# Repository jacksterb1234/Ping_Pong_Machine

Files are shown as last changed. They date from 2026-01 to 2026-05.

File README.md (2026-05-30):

# Ping Pong Machine — Table Tennis Serving Robot

A fully custom table tennis serving robot designed for serve-receive practice. Features dual-axis spin control (pitch and yaw), a printed spindexer, and a Bluetooth mobile app for wireless control. Powered entirely from a single USB-C connection.

## Features

- **Dual-axis spin control** — independent pitch and yaw adjustment for realistic serve variation
- **Printed spindexer** — feeds and spins balls for consistent delivery
- **Bluetooth control** via a custom mobile app (Expo/React Native) for easy wireless operation
- **USB-C powered** — single cable for full system power
- **Modular electronics design:**
  - USB-C PD power negotiation board
  - Motor and microcontroller breakout board
  - Buck voltage regulation board
- Designed and fabricated with **JLCPCB** for PCB production

## Repository Structure

```
Ping_Pong_Machine/
├── Kicad/               # KiCad PCB projects (power, motor breakout, buck reg)
├── Code/                # Microcontroller firmware and Bluetooth app code
├── CAD/                 # 3D-printable parts (spindexer, frame, wheels)
├── Sims/                # Simulations for board fit and assembly
└── ul_PTPS543021DRLR/   # Custom KiCad footprint
```

## Electronics

| Board | Function |
|---|---|
| USB-C PD board | Negotiates input voltage from USB-C PD source |
| Motor breakout | Drives launch and spin motors |
| MCU breakout | Hosts microcontroller and Bluetooth module |
| Buck regulator | Steps down voltage for logic-level components |

## Mobile App

Controlled via a custom **React Native (Expo)** app that connects over Bluetooth. The app allows users to adjust spin type, speed, and frequency from their phone—no physical controls on the machine required.

## Tools Used

- **KiCad** — PCB schematic and layout
- **JLCPCB** — PCB fabrication and SMT assembly
- **Fusion360 / SolidWorks** — Mechanical CAD (frame and launcher)
- **Expo (React Native)** — Mobile app development

## Author

**Jackson Barber** — [github.com/jacksterb1234](https://github.com/jacksterb1234)

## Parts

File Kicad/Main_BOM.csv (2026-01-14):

Id | Designator | Footprint | Quantity | Designation | Supplier and ref
1 | U5 | Vishay_MINICAST-3Pin | 1 | TSOP382xx
2 | C2,C3 | C_0603_1608Metric | 2 | 0.1u
3 | R1 | R_0603_1608Metric | 1 | 10k
4 | U3 | ESP32_30pin | 1 | ~
5 | C5,C1 | C_0603_1608Metric | 2 | 10u
6 | A1 | Pololu_Breakout-16_15.2x20.3mm | 1 | Pololu_Breakout_A4988
7 | C4 | C_0603_1608Metric | 1 | 100u
8 | C7 | C_0603_1608Metric | 1 | 2.2u
9 | J4,J5 | PinHeader_1x04_P2.54mm_Vertical | 2 | Conn_01x04_Pin
10 | C6 | C_0603_1608Metric | 1 | 0.01u
11 | J2,J1 | TerminalBlock_RND_205-00232_1x02_P5.08mm_Horizontal | 2 | Screw_Terminal_01x02
12 | U2 | TSSOP-16_4.4x5mm_P0.65mm | 1 | DRV8833PW
13 | J3 | TerminalBlock_Phoenix_MKDS-3-4-5.08_1x04_P5.08mm_Horizontal | 1 | Screw_Terminal_01x04

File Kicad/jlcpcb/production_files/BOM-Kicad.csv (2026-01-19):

Comment | Designator | Footprint | LCSC | Quantity
100nF | C2,C3 | C_0805_2012Metric_Pad1.18x1.45mm_HandSolder | C14663 | 2
10kΩ | R1 | R_0805_2012Metric_Pad1.20x1.40mm_HandSolder | C25804 | 1
10nF | C6 | C_0805_2012Metric_Pad1.18x1.45mm_HandSolder | C57112 | 1
10uF | C1,C5 | C_0805_2012Metric_Pad1.18x1.45mm_HandSolder | C19702 | 2
2.2uF | C7 | C_0805_2012Metric_Pad1.18x1.45mm_HandSolder | C23630 | 1
TSOP382xx | U5 | Vishay_MINICAST-3Pin |  | 1
~ | U3 | ESP32_30pin |  | 1
Pololu_Breakout_A4988 | A1 | Pololu_Breakout-16_15.2x20.3mm |  | 1
100u | C4 | C_Radial_D8.0mm_H11.5mm_P3.50mm |  | 1
Conn_01x04_Pin | J4 | PinHeader_1x04_P2.54mm_Vertical |  | 1
Screw_Terminal_01x02 | J2 | TerminalBlock_RND_205-00045_1x02_P5.00mm_Horizontal |  | 1
DRV8833PW | U2 | TSSOP-16_4.4x5mm_P0.65mm |  | 1
Screw_Terminal_01x02 | J1 | TerminalBlock_RND_205-00045_1x02_P5.00mm_Horizontal |  | 1
Screw_Terminal_01x04 | J3 | TerminalBlock_RND_205-00003_1x04_P5.00mm_Horizontal |  | 1
Conn_01x04_Pin | J5 | PinHeader_1x04_P2.54mm_Vertical |  | 1

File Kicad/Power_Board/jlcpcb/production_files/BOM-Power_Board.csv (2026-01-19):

Comment | Designator | Footprint | LCSC | Quantity
100kΩ | R4,R7 | R_0805_2012Metric_Pad1.20x1.40mm_HandSolder | C25803 | 2
100nF | C2,C3,C6 | C_0805_2012Metric_Pad1.18x1.45mm_HandSolder | C14663 | 3
100pF | C8 | C_0805_2012Metric_Pad1.18x1.45mm_HandSolder | C14858 | 1
10uF | C1 | C_0805_2012Metric_Pad1.18x1.45mm_HandSolder | C96446 | 1
22kΩ | R5 | R_0805_2012Metric_Pad1.20x1.40mm_HandSolder | C31850 | 1
22uF | C7 | C_0805_2012Metric_Pad1.18x1.45mm_HandSolder | C45783 | 1
47uF | C4 | C_0805_2012Metric_Pad1.18x1.45mm_HandSolder | C16780 | 1
5.1kΩ | R8 | R_0805_2012Metric_Pad1.20x1.40mm_HandSolder | C23186 | 1
68pF | C5 | C_0805_2012Metric_Pad1.18x1.45mm_HandSolder | C28262 | 1
6.8uH | L1 | L_TDK_VLS6045EX_VLS6045AF |  | 1
PTPS543021DRLR | U2 | DRL0006A-MFG |  | 1
Screw_Terminal_01x02 | J2 | TerminalBlock_RND_205-00045_1x02_P5.00mm_Horizontal |  | 1
4.7uH | L2 | L_TDK_VLS6045EX_VLS6045AF |  | 1
Conn_01x04_Pin | J1 | PinSocket_1x04_P2.54mm_Vertical |  | 1
PTPS543021DRLR | U1 | DRL0006A-MFG |  | 1

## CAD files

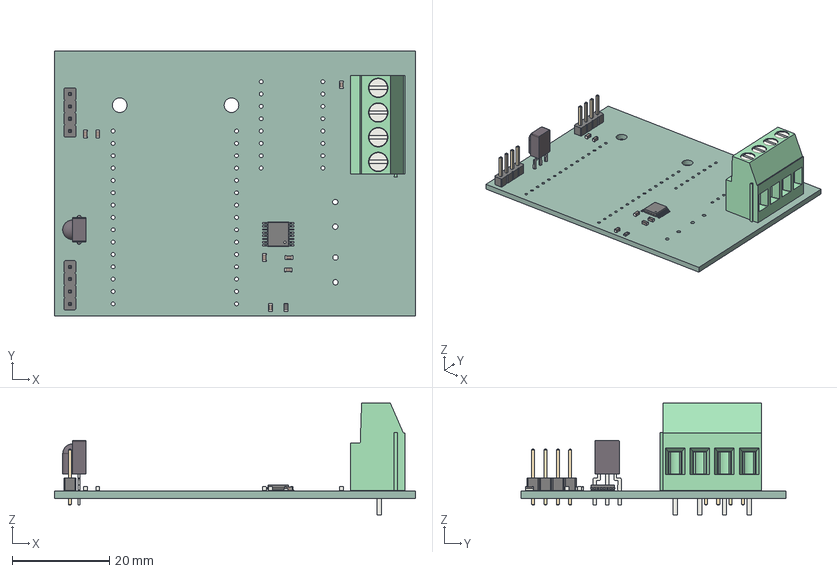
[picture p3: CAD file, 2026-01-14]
CAD/Boards/Main_Board.step
74.3 x 54.6 x 23.0 mm
Vishay_MINICAST-3Pin
C_0603_1608Metric x 7
R_0603_1608Metric
PinHeader_1x04_P2.54mm_Vertical x 2
TSSOP-16_4.4x5mm_P0.65mm
TerminalBlock_Phoenix_MKDS-3-4-5.08_1x04_P5.08mm_Horizontal
Kicad_PCB

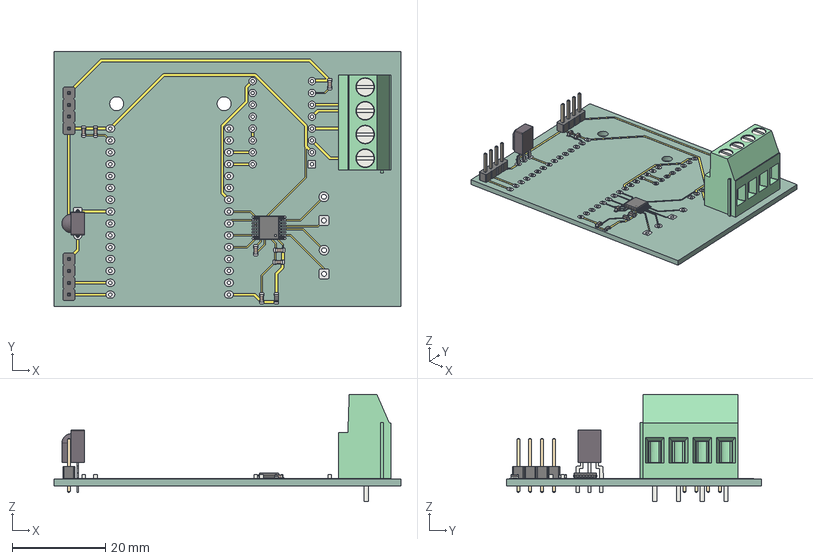
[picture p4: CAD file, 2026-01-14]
CAD/Boards/Main_For_Sim.step
74.3 x 54.6 x 23.0 mm
Vishay_MINICAST-3Pin
C_0603_1608Metric x 7
R_0603_1608Metric
PinHeader_1x04_P2.54mm_Vertical x 2
TSSOP-16_4.4x5mm_P0.65mm
TerminalBlock_Phoenix_MKDS-3-4-5.08_1x04_P5.08mm_Horizontal
Kicad_copper
Kicad_pad
Kicad_via
Kicad_PCB

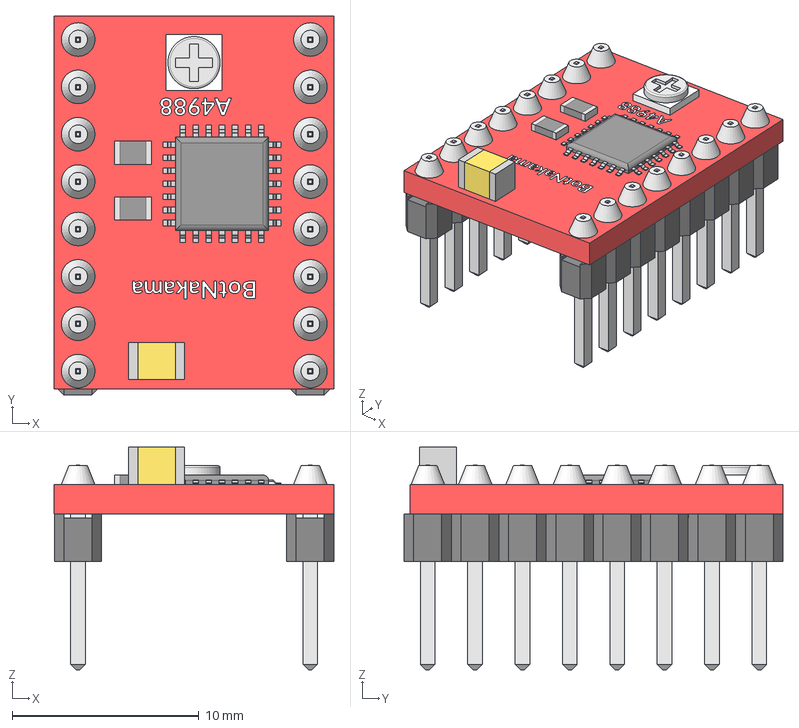
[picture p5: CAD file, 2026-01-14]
CAD/Boards/A4988.stp
15.0 x 20.3 x 11.9 mm
Integrado
Cubo001
BotNakama
A4988_1

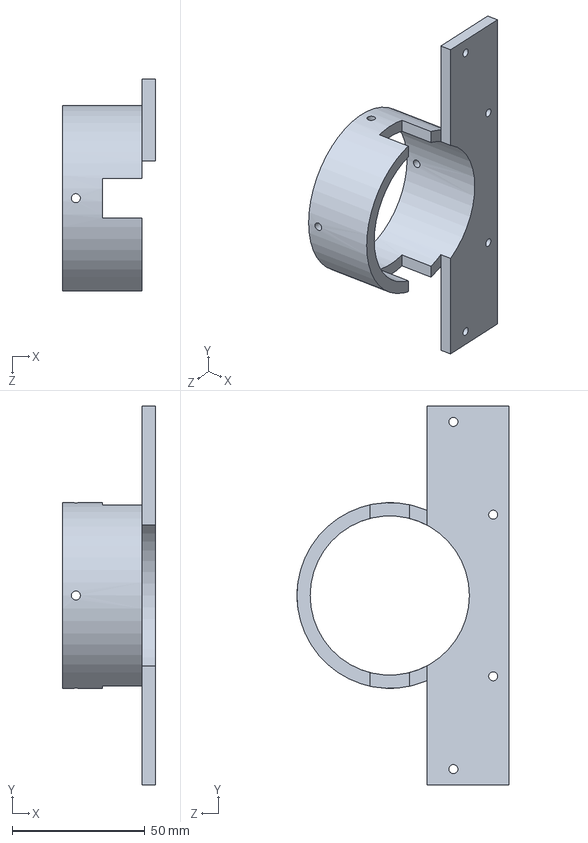
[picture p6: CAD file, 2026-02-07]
CAD/Ping_Pong_P004_Motor_Plate.SLDPRT
35.0 x 143.0 x 80.0 mm

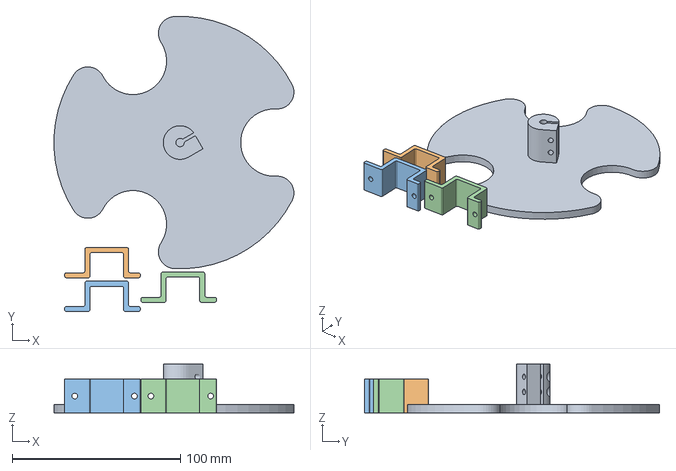
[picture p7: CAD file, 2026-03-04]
CAD/Prints/Ping_Pong_P003_Spindexer_Coupler_Print.3mf
142.6 x 175.3 x 29.0 mm
Ping_Pong_P003_Spindexer_Coupler_Print.STL
Ping_Pong_P005_Motor_Retainer_Print.STL x 3

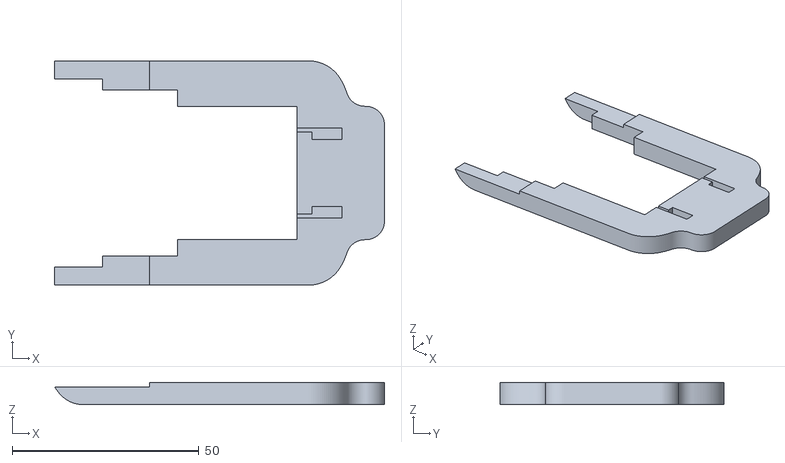
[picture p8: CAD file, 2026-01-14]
CAD/Boards/Base_to_1.5mm2.stl
88.3 x 60.0 x 6.00

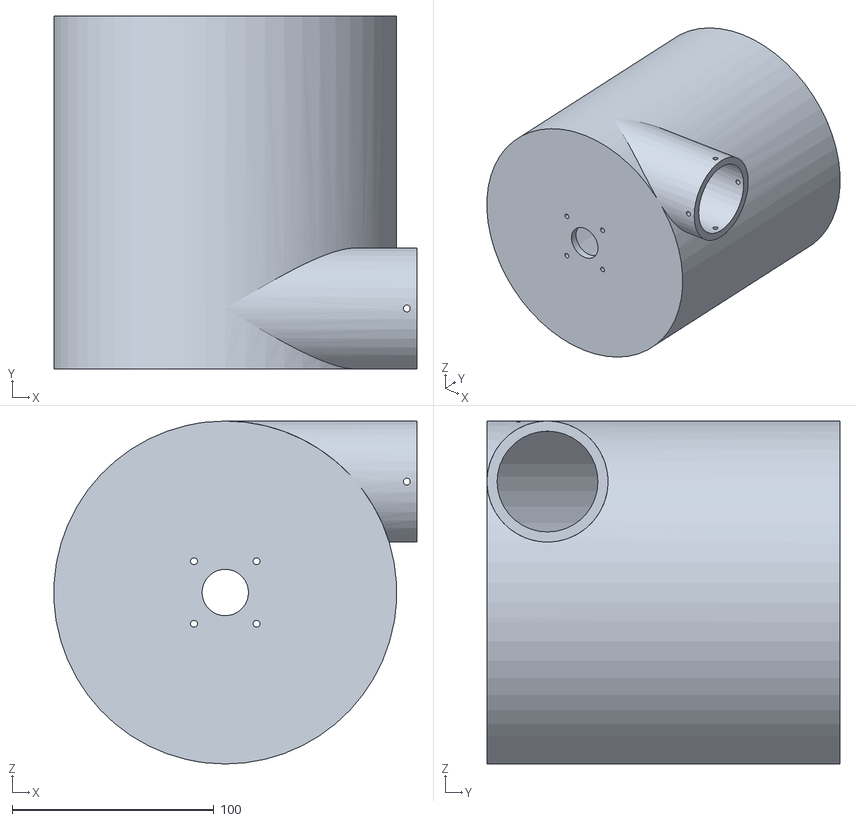
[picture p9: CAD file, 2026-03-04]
CAD/Prints/Ping_Pong_P002_Bin_Print.STL
179.9 x 175.0 x 170.0

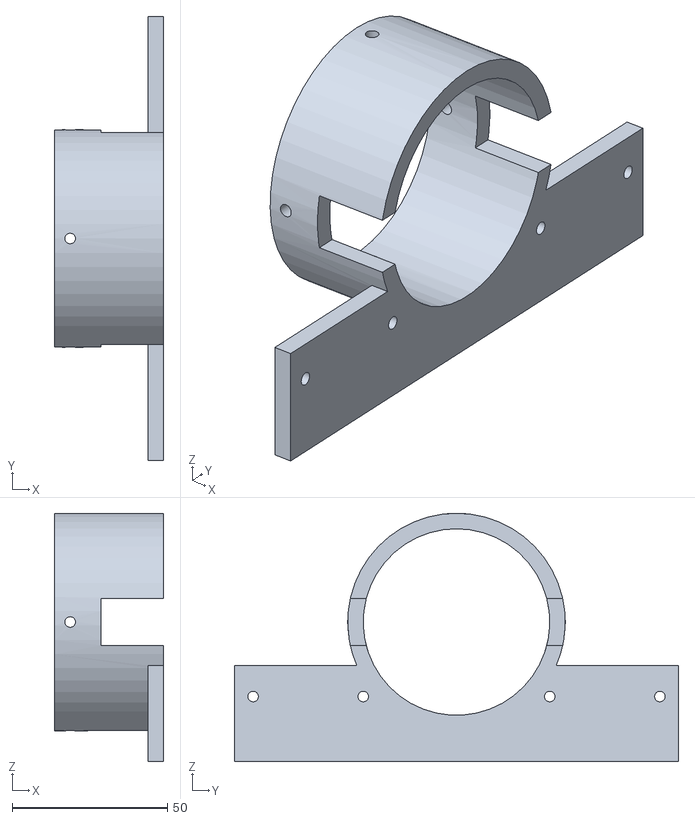
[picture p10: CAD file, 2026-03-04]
CAD/Prints/Ping_Pong_P004_Motor_Plate_Print.STL
35.0 x 143.0 x 80.0

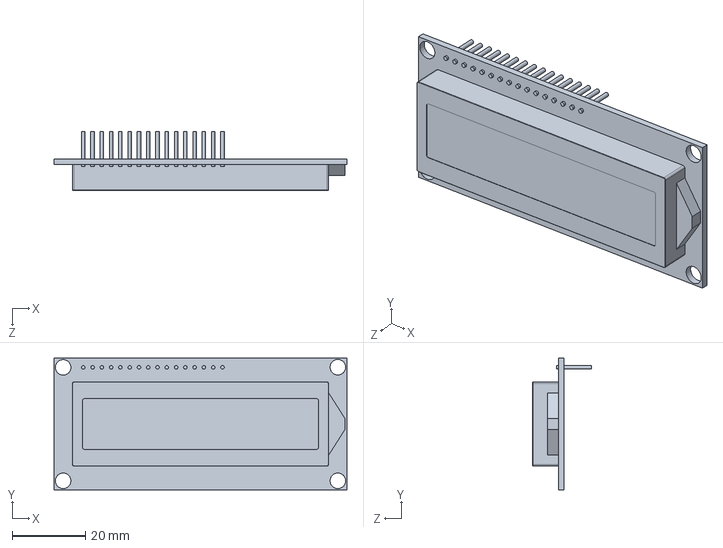
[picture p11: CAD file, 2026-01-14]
CAD/Boards/LCD.SLDPRT
80.0 x 36.0 x 16.0 mm

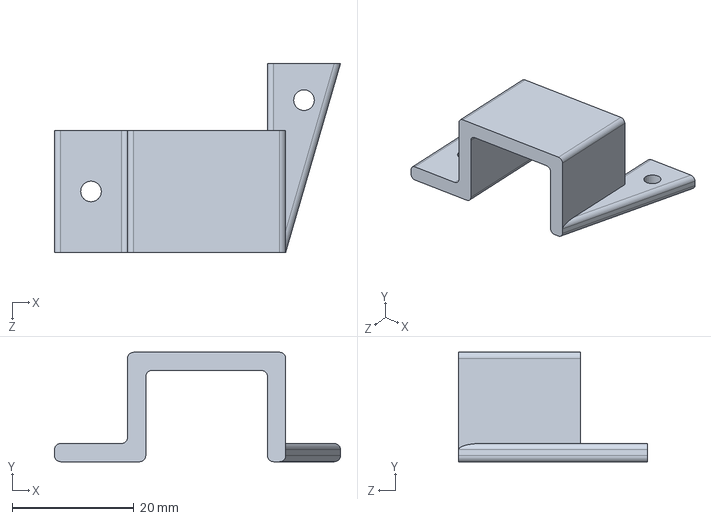
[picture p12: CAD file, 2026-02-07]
CAD/Ping_Pong_P005_Motor_Retainer.SLDPRT
47.0 x 18.0 x 31.0 mm

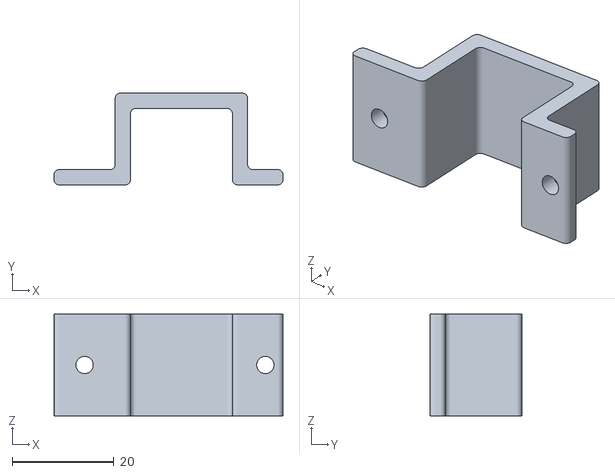
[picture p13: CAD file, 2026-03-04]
CAD/Prints/Ping_Pong_P005_Motor_Retainer_Print.STL
44.9 x 18.0 x 20.0

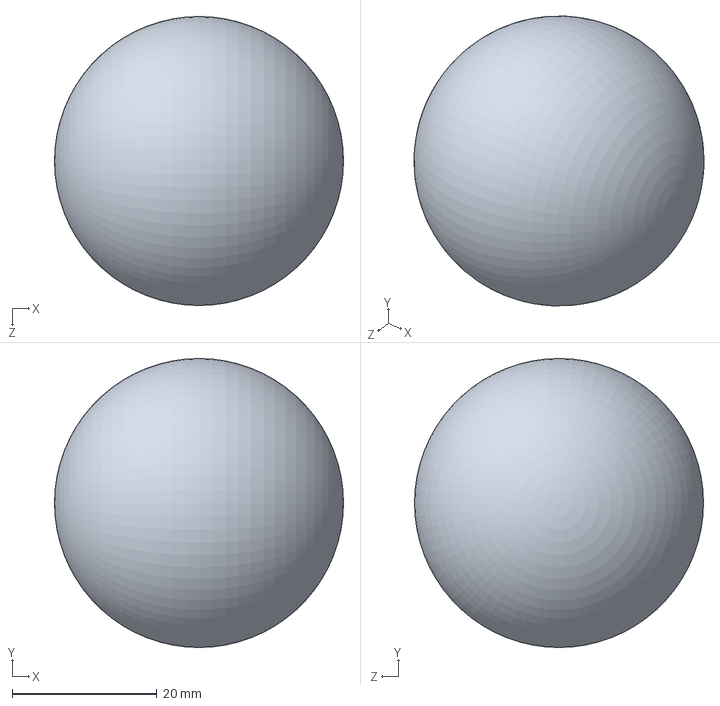
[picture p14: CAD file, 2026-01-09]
CAD/Ping_Pong_P001_Ball.SLDPRT
40.0 x 40.0 x 40.0 mm

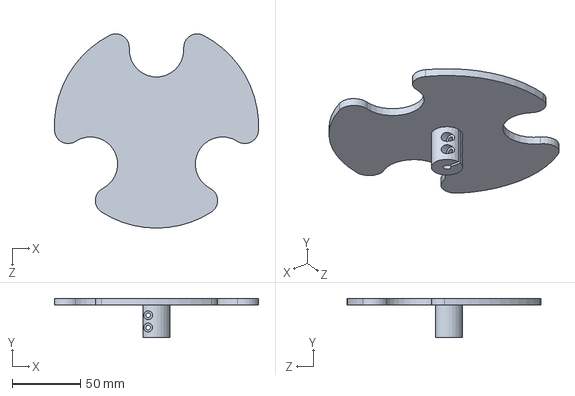
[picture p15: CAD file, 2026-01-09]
CAD/Ping_Pong_P003_Spindexer_Coupler.SLDPRT
149.9 x 29.0 x 142.7 mm

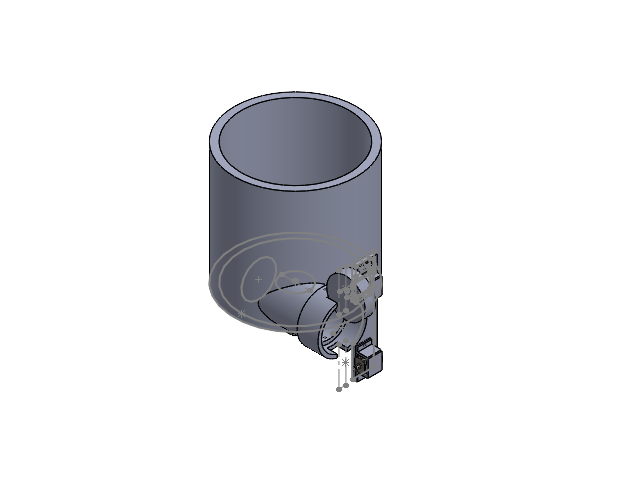
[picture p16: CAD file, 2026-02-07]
CAD/Ping_Pong_A001_MAIN.SLDASM
Ping_Pong_P002_Bin
Ping_Pong_P001_Ball
6627T91_Stepper Motor
Ping_Pong_P003_Spindexer_Coupler
Ping_Pong_P004_Motor_Plate
CommutatorHousing.STEP x 2
StatorHousing.STEP x 2
Gear6.STEP x 2
Ping_Pong_P005_Motor_Retainer
Ping_Pong_P006_Wheel_Mockup
MirrorPing_Pong_P005_Motor_Retainer

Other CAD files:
CAD/Boards/Ping_Pong_Board_A001_MAIN.SLDASM
CAD/Boards/R_0603_1608Metric_1.step.SLDPRT
CAD/MirrorPing_Pong_P005_Motor_Retainer.SLDPRT
CAD/Boards/R_0603_1608Metric_2.step.SLDPRT
CAD/6627T91_Stepper Motor.SLDPRT
CAD/Boards/C_0603_1608Metric_1.step.SLDPRT
CAD/Boards/C_0603_1608Metric_2.step.SLDPRT
CAD/Boards/DeWalt 10AH 20V Battery.step
CAD/Boards/L_0603_1608Metric_1.step.SLDPRT
CAD/Boards/PinHeader_1x04_P2.54mm_Vertical_1.step.SLDPRT
CAD/Boards/Power_Board.step
CAD/Boards/Power_Board_For_Sim.step
CAD/Boards/Power_Board_PCB_1.step.SLDPRT
CAD/Boards/TerminalBlock_Phoenix_MKDS-1,5-2-5.08_1x02_P5.08mm_Horizontal_1.step.SLDPRT
CAD/Boards/esp32_Wroom_30pins_C-Type.STEP
CAD/Ping_Pong_P002_Bin.SLDPRT
CAD/Ping_Pong_P006_Wheel_Mockup.SLDPRT
CAD/Prints/Ping_Pong_P003_Spindexer_Coupler_Print.STL

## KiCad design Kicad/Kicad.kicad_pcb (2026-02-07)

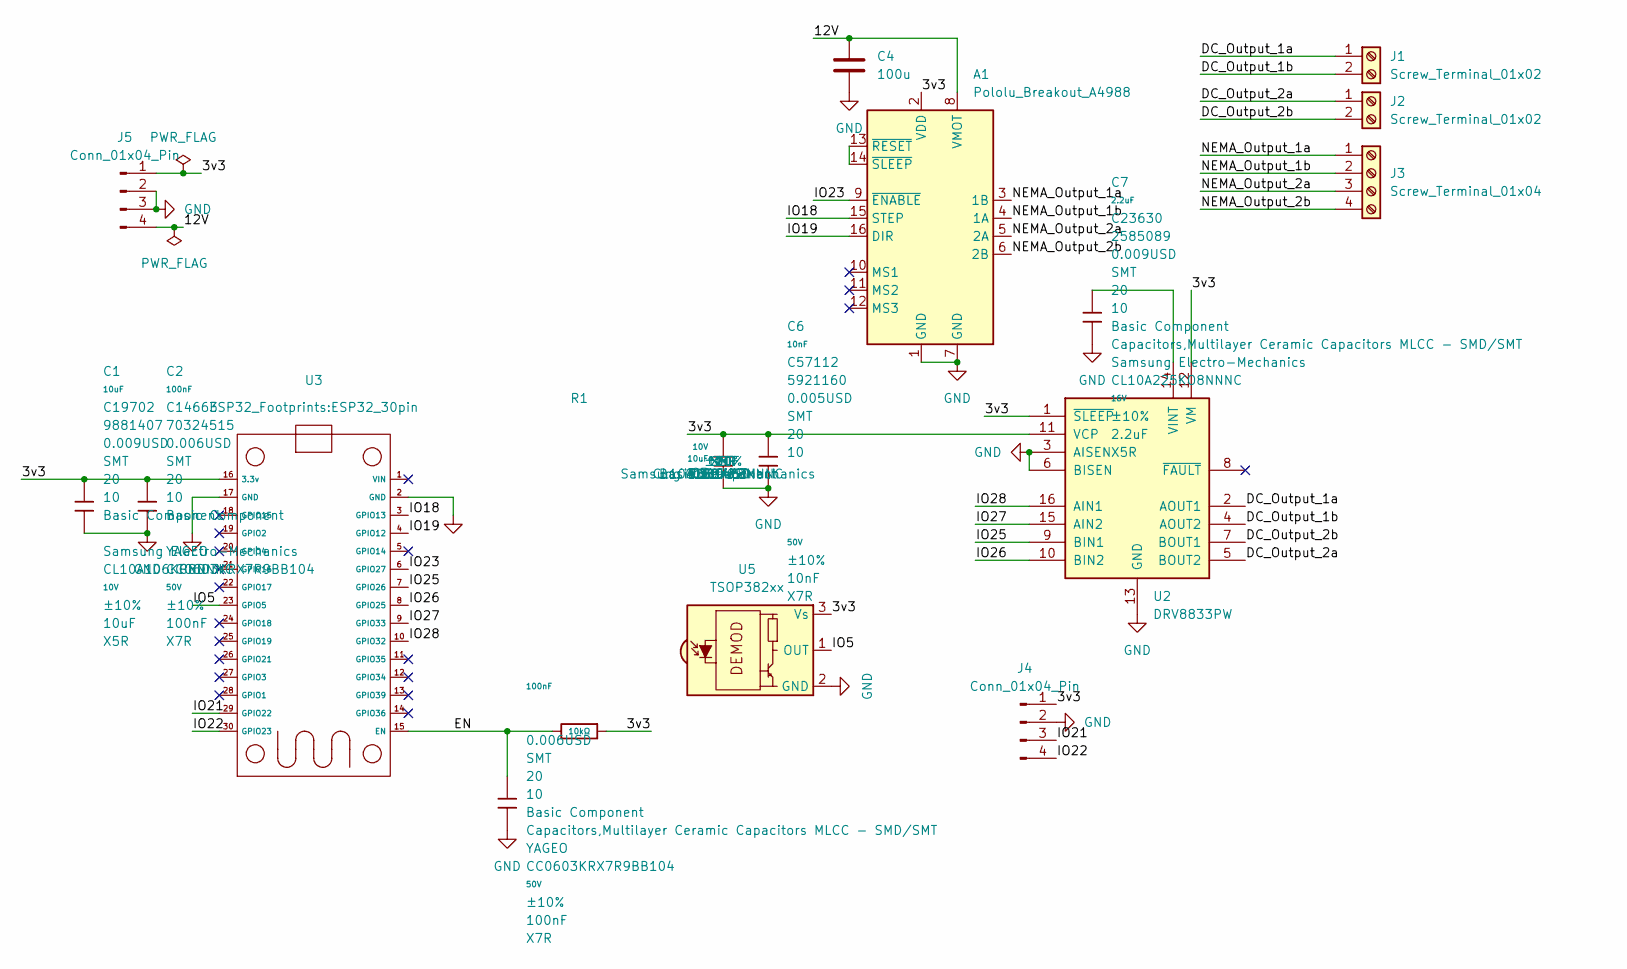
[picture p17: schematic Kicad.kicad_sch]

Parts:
A1: Pololu_Breakout_A4988; Pololu_Breakout-16_15.2x20.3mm
C1, C5: 10uF; C_0805_2012Metric_Pad1.18x1.45mm_HandSolder; Voltage Rated 10V; Tolerance ±10%; Part CL10A106KP8NNNC; LCSC C19702
C2, C3: 100nF; C_0805_2012Metric_Pad1.18x1.45mm_HandSolder; Voltage Rated 50V; Tolerance ±10%; Part CC0603KRX7R9BB104; LCSC C14663
C4: 100u; C_Radial_D8.0mm_H11.5mm_P3.50mm
C6: 10nF; C_0805_2012Metric_Pad1.18x1.45mm_HandSolder; Voltage Rated 50V; Tolerance ±10%; Part 0603B103K500NT; LCSC C57112
C7: 2.2uF; C_0805_2012Metric_Pad1.18x1.45mm_HandSolder; Voltage Rated 16V; Tolerance ±10%; Part CL10A225KO8NNNC; LCSC C23630
J1, J2: Screw_Terminal_01x02; TerminalBlock_RND_205-00045_1x02_P5.00mm_Horizontal
J3: Screw_Terminal_01x04; TerminalBlock_RND_205-00003_1x04_P5.00mm_Horizontal
J4, J5: Conn_01x04_Pin; PinHeader_1x04_P2.54mm_Vertical
R1: 10kΩ; R_0805_2012Metric_Pad1.20x1.40mm_HandSolder; Overload Voltage (Max) 75V; Tolerance ±1%; Part 0603WAF1002T5E; LCSC C25804
U2: DRV8833PW; TSSOP-16_4.4x5mm_P0.65mm
U3: ESP32_30pin
U5: TSOP382xx; Vishay_MINICAST-3Pin

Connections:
/3v3: A1.2 (VDD), C1.2, C2.2, C5.2, C6.2, J4.1, J5.1, R1.1, U2.1 (~SLEEP), U2.11 (VCP), U2.12 (VM), U3.16 (3.3v), U5.3 (Vs)
/12V: A1.8 (VMOT), C4.2, J5.4
/DC_Output_1a: J1.1, U2.2 (AOUT1)
/DC_Output_1b: J1.2, U2.4 (AOUT2)
/DC_Output_2a: J2.1, U2.5 (BOUT2)
/DC_Output_2b: J2.2, U2.7 (BOUT1)
/EN: C3.1, R1.2, U3.15 (EN)
/IO5: U3.23 (GPIO5), U5.1 (OUT)
/IO18: A1.15 (STEP), U3.3 (GPIO13)
/IO19: A1.16 (DIR), U3.4 (GPIO12)
/IO21: J4.3, U3.29 (GPIO22)
/IO22: J4.4, U3.30 (GPIO23)
/IO23: A1.9 (~ENABLE), U3.6 (GPIO27)
/IO25: U2.9 (BIN1), U3.7 (GPIO26)
/IO26: U2.10 (BIN2), U3.8 (GPIO25)
/IO27: U2.15 (AIN2), U3.9 (GPIO33)
/IO28: U2.16 (AIN1), U3.10 (GPIO32)
/NEMA_Output_1a: A1.3 (1B), J3.1
/NEMA_Output_1b: A1.4 (1A), J3.2
/NEMA_Output_2a: A1.5 (2A), J3.3
/NEMA_Output_2b: A1.6 (2B), J3.4
GND: A1.1 (GND), A1.7 (GND), C1.1, C2.1, C3.2, C4.1, C5.1, C6.1, C7.1, J4.2, J5.2, J5.3, U2.3 (AISEN), U2.6 (BISEN), U2.13 (GND), U3.2 (GND), U3.17 (GND), U5.2 (GND)
unnamed: A1.13 (~RESET), A1.14 (~SLEEP)
unnamed: C7.2, U2.14 (VINT)

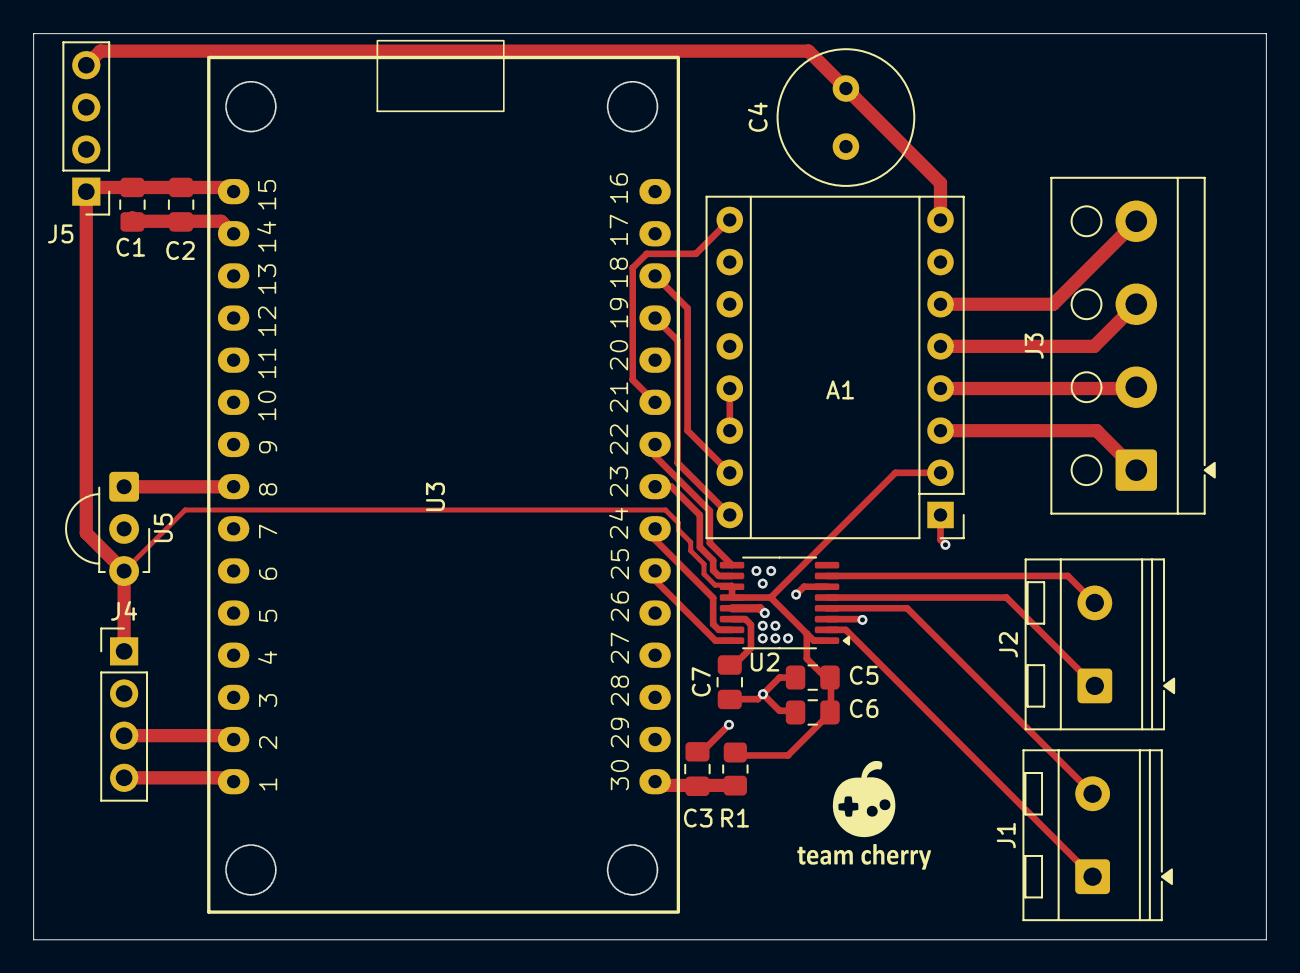
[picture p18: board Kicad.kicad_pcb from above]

Board: 2 copper layers, 74.3 x 54.6 mm, 17 parts (0 on the bottom side), 24 nets.

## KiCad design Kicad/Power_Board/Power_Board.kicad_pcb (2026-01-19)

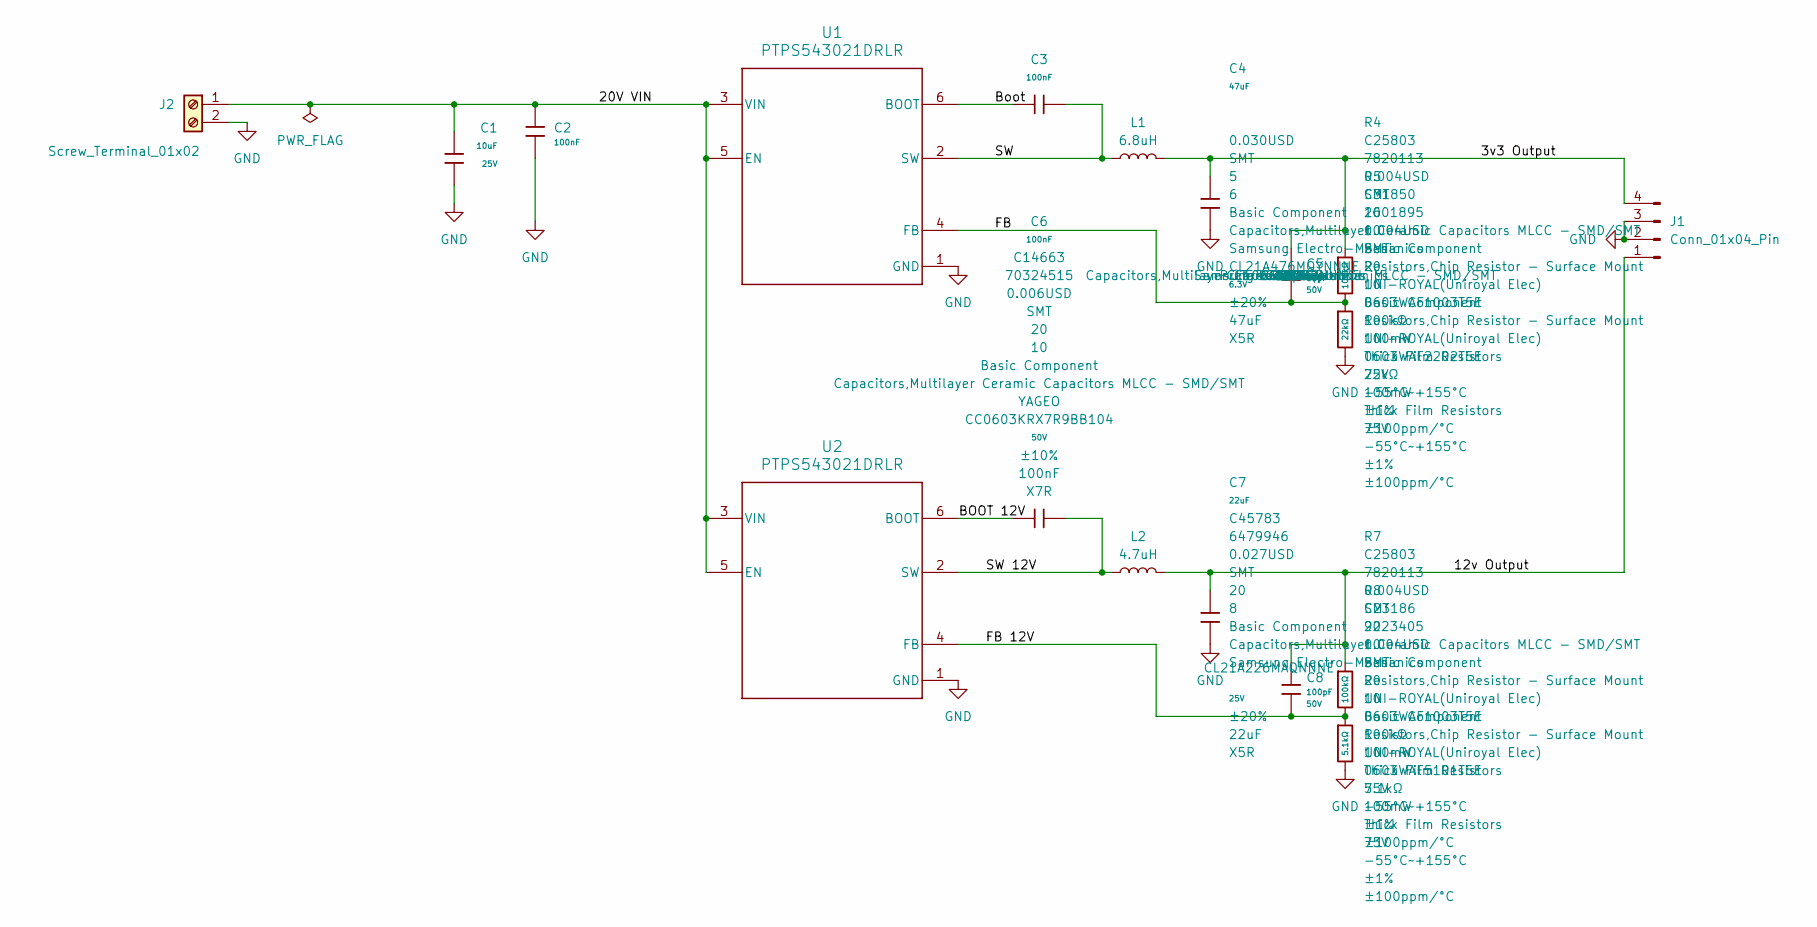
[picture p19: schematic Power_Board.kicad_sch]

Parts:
C1: 10uF; C_0805_2012Metric_Pad1.18x1.45mm_HandSolder; Voltage Rated 25V; Tolerance ±20%; Part CL10A106MA8NRNC; LCSC C96446
C2, C3, C6: 100nF; C_0805_2012Metric_Pad1.18x1.45mm_HandSolder; Voltage Rated 50V; Tolerance ±10%; Part CC0603KRX7R9BB104; LCSC C14663
C4: 47uF; C_0805_2012Metric_Pad1.18x1.45mm_HandSolder; Voltage Rated 6.3V; Tolerance ±20%; Part CL21A476MQYNNNE; LCSC C16780
C5: 68pF; C_0805_2012Metric_Pad1.18x1.45mm_HandSolder; Voltage Rated 50V; Tolerance ±5%; Part CL10C680JB8NNNC; LCSC C28262
C7: 22uF; C_0805_2012Metric_Pad1.18x1.45mm_HandSolder; Voltage Rated 25V; Tolerance ±20%; Part CL21A226MAQNNNE; LCSC C45783
C8: 100pF; C_0805_2012Metric_Pad1.18x1.45mm_HandSolder; Voltage Rated 50V; Tolerance ±5%; Part CL10C101JB8NNNC; LCSC C14858
J1: Conn_01x04_Pin; PinSocket_1x04_P2.54mm_Vertical
J2: Screw_Terminal_01x02; TerminalBlock_RND_205-00045_1x02_P5.00mm_Horizontal
L1: 6.8uH; L_TDK_VLS6045EX_VLS6045AF
L2: 4.7uH; L_TDK_VLS6045EX_VLS6045AF
R4, R7: 100kΩ; R_0805_2012Metric_Pad1.20x1.40mm_HandSolder; Overload Voltage (Max) 75V; Tolerance ±1%; Part 0603WAF1003T5E; LCSC C25803
R5: 22kΩ; R_0805_2012Metric_Pad1.20x1.40mm_HandSolder; Overload Voltage (Max) 75V; Tolerance ±1%; Part 0603WAF2202T5E; LCSC C31850
R8: 5.1kΩ; R_0805_2012Metric_Pad1.20x1.40mm_HandSolder; Overload Voltage (Max) 75V; Tolerance ±1%; Part 0603WAF5101T5E; LCSC C23186
U1, U2: PTPS543021DRLR; DRL0006A-MFG

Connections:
/3v3 Output: C4.1, C5.1, J1.4, L1.2, R4.1
/12v Output: C7.1, C8.1, J1.1, L2.2, R7.1
/20V VIN: C1.1, C2.1, J2.1, U1.3 (VIN), U1.5 (EN), U2.3 (VIN), U2.5 (EN)
/BOOT 12V: C6.1, U2.6 (BOOT)
/Boot: C3.1, U1.6 (BOOT)
/FB: C5.2, R4.2, R5.1, U1.4 (FB)
/FB 12V: C8.2, R7.2, R8.1, U2.4 (FB)
/SW: C3.2, L1.1, U1.2 (SW)
/SW 12V: C6.2, L2.1, U2.2 (SW)
GND: C1.2, C2.2, C4.2, C7.2, J1.2, J1.3, J2.2, R5.2, R8.2, U1.1 (GND), U2.1 (GND)

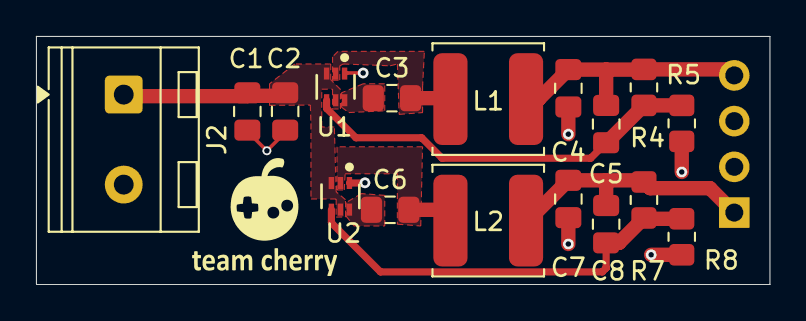
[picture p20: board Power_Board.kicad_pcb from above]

Board: 2 copper layers, 40.8 x 13.8 mm, 18 parts (1 on the bottom side), 10 nets.

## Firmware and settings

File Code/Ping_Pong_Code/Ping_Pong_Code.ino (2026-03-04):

#include <Arduino.h>

#define DECODE_NEC
#include <IRremote.hpp>

#include <Wire.h>
#include <LiquidCrystal_I2C.h>

// --- BLE ---
#include <BLEDevice.h>
#include <BLEServer.h>
#include <BLEUtils.h>
#include <BLE2902.h>

// -------------------- PINS --------------------
const int IR_PIN = 5;

// A4988
const int STEP_PIN = 13;
const int DIR_PIN  = 12;
const int EN_PIN   = 27;
const bool A4988_ENABLE_ACTIVE_LOW = true;

// DRV8833
const int AIN1 = 32;
const int AIN2 = 33;
const int BIN1 = 26;
const int BIN2 = 25;

// LCD
const int LCD_ADDR = 0x27;
// Note: you had (LCD_ADDR, 22, 23) in your code, which is unusual for LiquidCrystal_I2C.
// If that worked for you, keep it. If not, typical call is (LCD_ADDR, 16, 2).
LiquidCrystal_I2C lcd(LCD_ADDR, 16, 2);

// DC Speed Setup
const uint32_t DC_PWM_FREQ = 20000;
const uint8_t  DC_PWM_RES  = 8;
uint8_t dc1Speed = 180;
uint8_t dc2Speed = 180;

// IR commands
const uint8_t IR_CMD_TOGGLE_STEPPER = 0x10;
const uint8_t IR_CMD_TOGGLE_DCS     = 0x11;
const uint8_t IR_CMD_SERVE_ONE      = 0x12;
const uint8_t IR_CMD_MOTOR1_SPDUP   = 0x13;
const uint8_t IR_CMD_MOTOR1_SLWDWN  = 0x14;
const uint8_t IR_CMD_MOTOR2_SPDUP   = 0x15;
const uint8_t IR_CMD_MOTOR2_SLWDWN  = 0x16;

// Stepper control
const int STEPS_PER_SERVE = 800;
const int STEP_DELAY_US   = 800;

// State
bool stepperEnabled = false;
bool dcMotorsOn     = false;
int  ballsServed    = 0;

// --- BLE UUIDs (match Expo app) ---
#define SERVICE_UUID   "0000FFFF-0000-1000-8000-00805F9B34FB"
#define CMD_CHAR_UUID  "0000FF01-0000-1000-8000-00805F9B34FB"

BLECharacteristic *cmdChar = nullptr;

// Continuous serve state
bool     continuousOn        = false;
uint32_t continuousIntervalMs = 400;
uint32_t lastServeMs         = 0;

// -------------------- LCD --------------------
void lcdUpdate() {
  lcd.clear();
  lcd.setCursor(0, 0);
  lcd.print("Served: ");
  lcd.print(ballsServed);

  lcd.setCursor(0, 1);
  lcd.print("ST:");
  if (stepperEnabled) lcd.print("ON ");
  else                lcd.print("OFF");

  lcd.print(" DC:");
  if (dcMotorsOn) lcd.print("ON ");
  else            lcd.print("OFF ");

  lcd.print(dc1Speed / 255.0f * 100.0f, 0);
  lcd.print("%,");
  lcd.print(dc2Speed / 255.0f * 100.0f, 0);
  lcd.print("%");
}

// -------------------- Stepper --------------------
void setStepperEnabled(bool on) {
  stepperEnabled = on;
  pinMode(EN_PIN, OUTPUT);

  if (A4988_ENABLE_ACTIVE_LOW) {
    if (on) digitalWrite(EN_PIN, LOW);
    else    digitalWrite(EN_PIN, HIGH);
  } else {
    if (on) digitalWrite(EN_PIN, HIGH);
    else    digitalWrite(EN_PIN, LOW);
  }
}

void stepperMoveSteps(int steps, bool dir) {
  if (!stepperEnabled) return;

  digitalWrite(DIR_PIN, dir ? HIGH : LOW);

  for (int i = 0; i < steps; i++) {
    digitalWrite(STEP_PIN, HIGH);
    delayMicroseconds(STEP_DELAY_US);
    digitalWrite(STEP_PIN, LOW);
    delayMicroseconds(STEP_DELAY_US);
  }
}

// -------------------- DC motors --------------------
void setDc1Speed() {
  digitalWrite(AIN2, LOW);
  analogWrite(AIN1, dc1Speed);
}

void setDc2Speed() {
  digitalWrite(BIN2, LOW);
  analogWrite(BIN1, dc2Speed);
}

void toggleDcMotors() {
  if (dcMotorsOn) {
    analogWrite(AIN1, 0);
    analogWrite(AIN2, 0);
    analogWrite(BIN1, 0);
    analogWrite(BIN2, 0);
  } else {
    setDc1Speed();
    setDc2Speed();
  }
  dcMotorsOn = !dcMotorsOn;
}

// -------------------- Serve --------------------
void serveOneBall() {
  if (!stepperEnabled) setStepperEnabled(true);
  stepperMoveSteps(STEPS_PER_SERVE, true);
  ballsServed++;
  lcdUpdate();
}

// -------------------- IR --------------------
void handleIrCommand(uint8_t cmd) {
  if (cmd == IR_CMD_TOGGLE_STEPPER) {
    setStepperEnabled(!stepperEnabled);
  } else if (cmd == IR_CMD_TOGGLE_DCS) {
    toggleDcMotors();
  } else if (cmd == IR_CMD_SERVE_ONE) {
    serveOneBall();
  } else if (cmd == IR_CMD_MOTOR1_SPDUP) {
    dc1Speed = min<uint8_t>(255, dc1Speed + 25);
    setDc1Speed();
  } else if (cmd == IR_CMD_MOTOR1_SLWDWN) {
    dc1Speed = max<uint8_t>(0, dc1Speed - 25);
    setDc1Speed();
  } else if (cmd == IR_CMD_MOTOR2_SPDUP) {
    dc2Speed = min<uint8_t>(255, dc2Speed + 25);
    setDc2Speed();
  } else if (cmd == IR_CMD_MOTOR2_SLWDWN) {
    dc2Speed = max<uint8_t>(0, dc2Speed - 25);
    setDc2Speed();
  }
  lcdUpdate();
}

// -------------------- BLE command handling --------------------
void handleBleCommand(const String &json) {
  Serial.print("BLE cmd: ");
  Serial.println(json);

  if (json.indexOf("\"type\":\"SERVE_ONE\"") >= 0) {
    serveOneBall();
  }
  else if (json.indexOf("\"type\":\"TOGGLE_DCS\"") >= 0) {
    toggleDcMotors();
    lcdUpdate();
  }
  else if (json.indexOf("\"type\":\"TOGGLE_STEPPER\"") >= 0) {
    setStepperEnabled(!stepperEnabled);
    lcdUpdate();
  }
  else if (json.indexOf("\"type\":\"MOTOR1_SPDUP\"") >= 0) {
    dc1Speed = min<uint8_t>(255, dc1Speed + 25);
    setDc1Speed();
    lcdUpdate();
  }
  else if (json.indexOf("\"type\":\"MOTOR1_SLWDWN\"") >= 0) {
    dc1Speed = max<uint8_t>(0, dc1Speed - 25);
    setDc1Speed();
    lcdUpdate();
  }
  else if (json.indexOf("\"type\":\"MOTOR2_SPDUP\"") >= 0) {
    dc2Speed = min<uint8_t>(255, dc2Speed + 25);
    setDc2Speed();
    lcdUpdate();
  }
  else if (json.indexOf("\"type\":\"MOTOR2_SLWDWN\"") >= 0) {
    dc2Speed = max<uint8_t>(0, dc2Speed - 25);
    setDc2Speed();
    lcdUpdate();
  }
  else if (json.indexOf("\"type\":\"START_CONTINUOUS\"") >= 0) {
    int idx = json.indexOf("\"intervalMs\":");
    if (idx >= 0) {
      int start = idx + String("\"intervalMs\":").length();
      int end = json.indexOf("}", start);
      if (end < 0) end = json.length();
      String num = json.substring(start, end);
      num.trim();
      uint32_t val = num.toInt();
      if (val >= 150 && val <= 3000) {
        continuousIntervalMs = val;
      }
    }
    continuousOn  = true;
    lastServeMs   = millis();
    Serial.println("Continuous mode: ON");
  }
  else if (json.indexOf("\"type\":\"STOP_CONTINUOUS\"") >= 0) {
    continuousOn = false;
    Serial.println("Continuous mode: OFF");
  }
  else {
    Serial.println("Unknown BLE command");
  }
}

class CommandCallback : public BLECharacteristicCallbacks {
  void onWrite(BLECharacteristic *c) override {
    String value = c->getValue();
    if (value.isEmpty()) return;
    String json(value.c_str());
    handleBleCommand(json);
  }
};

// -------------------- Setup --------------------
void setup() {
  Serial.begin(115200);

  // Stepper
  pinMode(STEP_PIN, OUTPUT);
  pinMode(DIR_PIN, OUTPUT);
  setStepperEnabled(false);

  // DC pins
  pinMode(AIN1, OUTPUT);
  pinMode(AIN2, OUTPUT);
  pinMode(BIN1, OUTPUT);
  pinMode(BIN2, OUTPUT);

  // DC PWM (adjust if your core uses ledcAttachPin style instead)
  analogWriteResolution(AIN1, DC_PWM_RES);
  analogWriteFrequency(AIN1, DC_PWM_FREQ);
  analogWriteResolution(BIN1, DC_PWM_RES);
  analogWriteFrequency(BIN1, DC_PWM_FREQ);

  digitalWrite(AIN2, LOW);
  digitalWrite(BIN2, LOW);
  analogWrite(AIN1, 0);
  analogWrite(BIN1, 0);

  // LCD
  lcd.init();
  lcd.backlight();
  lcdUpdate();

  // IR
  IrReceiver.begin(IR_PIN, DISABLE_LED_FEEDBACK);

  // BLE
  BLEDevice::init("PingPongRobot");
  BLEServer *server = BLEDevice::createServer();
  BLEService *service = server->createService(SERVICE_UUID);

  cmdChar = service->createCharacteristic(
    CMD_CHAR_UUID,
    BLECharacteristic::PROPERTY_WRITE | BLECharacteristic::PROPERTY_WRITE_NR
  );
  cmdChar->setCallbacks(new CommandCallback());

  service->start();

  BLEAdvertising *adv = BLEDevice::getAdvertising();
  adv->addServiceUUID(SERVICE_UUID);
  adv->setScanResponse(true);
  adv->setMinPreferred(0x06);
  adv->setMinPreferred(0x12);
  BLEDevice::startAdvertising();

  Serial.println("BLE advertising as PingPongRobot");
}

// -------------------- Loop --------------------
void loop() {
  // IR handling (unchanged)
  if (IrReceiver.decode()) {
    IrReceiver.printIRResultShort(&Serial);
    if ((IrReceiver.decodedIRData.flags & IRDATA_FLAGS_IS_REPEAT) == 0) {
      uint8_t cmd = IrReceiver.decodedIRData.command;
      handleIrCommand(cmd);
    }
    IrReceiver.resume();
  }

  // Continuous serve mode
  if (continuousOn) {
    uint32_t now = millis();
    if (now - lastServeMs >= continuousIntervalMs) {
      lastServeMs = now;
      serveOneBall();
    }
  }
}

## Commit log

2026-01-09 Updated File Structure
    [6627T91_Stepper Motor.SLDPRT, Bin.SLDPRT, MirrorPing_Pong_P005_Motor_Retainer.SLDPRT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]
2026-01-10 Added Power Board
    [Kicad.kicad_sch, Power_Board.kicad_pcb, Power_Board.kicad_sch]
2026-01-11 Updated schematic for main board
    [Kicad.kicad_pcb, Kicad.kicad_sch, Power_Board.kicad_sch]
2026-01-12 Main Board v1
    [Kicad.kicad_pcb, Kicad.kicad_sch, Power_Board.kicad_pcb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]
2026-01-14 Created cad for how the boards will fit together
    [A4988.stp, Base_to_1.5mm2.stl, C_0603_1608Metric_1.step.SLDPRT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]
2026-01-18 Wrote v1 of the code, final version of boards
    [BOM-Kicad.csv, BOM-Power_Board.csv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]
2026-01-19 Updated to use 0805 instead of JLC assembly
    [BOM-Kicad.csv, BOM-Power_Board.csv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]
2026-02-07 Modified Motor Mounting
    [Kicad.kicad_pcb, MirrorPing_Pong_P005_Motor_Retainer.SLDPRT, Ping_Pong_A001_MAIN.SLDASM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]
2026-03-04 Updated Power Board
    [BOM-Kicad.csv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]
